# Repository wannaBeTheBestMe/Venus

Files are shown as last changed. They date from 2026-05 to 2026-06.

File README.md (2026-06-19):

# Venus — autonomous explore-and-map robot (CBL Team 6)

A PYNQ-Z2 differential-drive robot that autonomously explores a black-tape-bounded arena, finds and
classifies rock samples (size / colour / temperature), avoids cliffs and mountains, and streams its
findings to a **PyQt6 ground-station UI** that draws a live map.

This README is the **operational "how to run it" guide**. For the *how it works*:
- **[OVERVIEW.md](OVERVIEW.md)** — plain-language description of the robot and mission.
- **[ALGORITHM.md](ALGORITHM.md)** — technical reference: the EXPLORE loop, sensors, calibration, and the
  **full command + message protocol** (§10).

Active code: firmware in `motors_newest/` (C on libpynq); ground station in `UI_code.py` (PyQt6).

---

## 1. Prerequisites
- **Robot:** PYNQ-Z2 reachable over SSH at `student@10.43.0.1` (Mac link interface `en6` → board `10.43.0.1`).
  Passwordless key at `~/.ssh/pynq_key` (password is `student` if the key isn't installed).
- **Ground station (laptop):** the venv `Venus/.venv` with PyQt6 + paho-mqtt + numpy. Create it once:
  ```bash
  sh .claude/skills/launch-robot-stack/setup_venv.sh    # makes Venus/.venv and installs the 3 deps
  ```
- MQTT broker `mqtt.ics.ele.tue.nl:1883`, topics `/pynqbridge/{41|80}/send|recv` (via the on-robot ESP32).

## 2. Build & deploy the firmware (on the board)
libpynq lives **on the PYNQ**, so the firmware is built there. Stop any running `./main` first (you cannot
overwrite a running binary):
```bash
# from this Venus/ directory
ssh -i ~/.ssh/pynq_key -o StrictHostKeyChecking=no student@10.43.0.1 "pkill -f motors_newest/main; true"
scp -i ~/.ssh/pynq_key motors_newest/*.c motors_newest/*.h motors_newest/student-startup.sh \
    student@10.43.0.1:~/libpynq-5EID0-2023-v0.3.0/applications/motors_newest/
ssh -i ~/.ssh/pynq_key student@10.43.0.1 \
    "cd ~/libpynq-5EID0-2023-v0.3.0/applications/motors_newest && make clean && make"
```
The Makefile's `end.mk` applies the needed Linux capabilities (`setcap cap_sys_rawio,cap_sys_nice+ep`).
Verify with `getcap ./main`.

## 3. Run
**Easiest — the launcher skill** (opens two iTerm2 tabs: firmware over SSH + the UI in its venv):
```
/launch-robot-stack
```
**Manual — two terminals:**
```bash
# Terminal A (robot firmware)
ssh -i ~/.ssh/pynq_key student@10.43.0.1 \
    "cd ~/libpynq-5EID0-2023-v0.3.0/applications/motors_newest && ./main"
# Terminal B (ground station)
source Venus/.venv/bin/activate && python UI_code.py
```
**Autonomy on boot:** when `./main` starts *and a calibration is loaded*, it auto-enters EXPLORE after a
~5 s settle. Send **`S`** or **`HOLD`** in that window to drop to interactive command mode instead.
The UI only **listens** — operator commands go to the robot over MQTT.

## 4. First-time calibration — REQUIRED
The cliff monitor and autonomy are gated on a loaded black/white calibration. Before anything else:
```
CALBLACK     # follow the prompts: show the WHITE floor, then the BLACK tape
```
It persists to `/home/student/calblack.cfg` and reloads on boot. `CALRESET` reverts to compile-time defaults.
If you see **"cliff monitor INACTIVE until calibrated"**, run `CALBLACK`.

## 5. Common commands (send from the UI command box)
Full list + message protocol in **[ALGORITHM.md](ALGORITHM.md) §10**.

| Command | Does |
|---|---|
| `EXPLORE` | Run the full autonomous explore-and-map mission |
| `CALBLACK` / `CALRESET` | Calibrate / reset black-tape detection |
| `SWEEPQ` | 180° object sweep (reports detected objects) |
| `O` | Sweep → approach the first object → classify (size/colour/temp) |
| `RSC` | Re-sweep relocalization (heading-drift + POSFIX check) |
| `F` / `FB` | Forward until cliff / forward until an obstacle |
| `R` / `L` / `U` | Turn right 90° / left 90° / 180° |
| `MTN` | Mountain-avoidance test (strafe; halts on tape) |
| `SHL,n` / `SHR,n` | Strafe left / right n cycles |
| `TEMP` | Live temperature readout (until `S`) |
| `S` / `HOLD` | Stop the current action |
| `LOGON` / `LOGOFF` | Wireless log stream on / off |

Colour-sensor (TCS3200) demo commands also exist — `RGB`, `HSV`, `CMYK`, `SCALE,<0-3>`, `INTEG,<n>`, `WB`,
`CHROMA`, `DOM`, `NEAREST` — see ALGORITHM.md.

## 6. Two boards
A single binary serves both robots; it reads the robot id from **`~/robot_id`** at boot (falls back to `41`).
The UI supports robots 41 and 80 simultaneously; `MQTT_SAT.py` is the sole inter-robot relay.

## 7. Troubleshooting
- **Board unreachable:** `ping 10.43.0.1`; on a host-key error after an IP reuse, `ssh-keygen -R 10.43.0.1`.
- **UI won't start / `ModuleNotFoundError`:** run `setup_venv.sh`, then `Venus/.venv/bin/python -c "import PyQt6, paho.mqtt.client, numpy"`.
- **Robot won't move / "cliff monitor INACTIVE":** run `CALBLACK` (uncalibrated boots skip autonomy by design).
- **`make` fails with "text file busy" (ETXTBSY):** a `./main` is still running — stop it first (§2).

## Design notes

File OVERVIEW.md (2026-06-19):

# Venus — a robot that explores on its own and maps what it finds

> **MAINTENANCE:** This is a living, plain-language overview of the project written for **readers who
> are not involved in it** — anyone who wants to understand what the robot does without reading the
> code. **Keep it current whenever the robot's behaviour or mission changes**, and update it in the
> **same change** as the code and as its technical sibling [`ALGORITHM.md`](ALGORITHM.md).
> `ALGORITHM.md` is the detailed source of truth (for people working on the project); this file is its
> jargon-free projection. If you edit one, refresh the other so they never disagree, and keep this one
> free of code names, file paths, and protocol detail.

---

## What this is

Venus is a small **autonomous robot** — it drives itself, with no human steering it. You place it in a
walled-off area it has never seen, switch it on, and it sets off on its own: wandering the space,
finding objects, measuring each one, watching out for dangers, and continuously radioing what it
learns back to a laptop, which draws a live map. By the end you have a picture of where everything is,
without anyone ever touching a controller.

## The mission

The robot works inside an arena about **1.5 by 1.5 metres**, ringed by an edge it must not cross.
Its job, entirely on its own, is to:

- **Explore** the whole area.
- **Find an unknown number of "rocks"** (small cube-shaped objects) and, for each one, report its
  **size, colour, and temperature**, and **where it is**.
- **Avoid "mountains"** — large obstacles (think cardboard boxes) it must not bump into.
- **Never fall off a "cliff."** The arena's edges and any interior drop-offs are marked with **black
  tape on the floor**. Driving over the tape means falling — and that ends the mission. So black tape
  is an absolute "do not cross."
- **Send everything home** so a laptop can build the map in real time.

It must do all of this starting from any position, the moment it powers on — no cable, no operator
typing commands during the run.

## What's on the robot

- **Two driven wheels** (plus a small trailing wheel for balance) let it move and turn in place.
- A **downward-looking sensor** that tells floor from black tape — its cliff detector. Crucially it
  sits **ahead of the wheels**, so it spots an edge a little before a wheel would reach it.
- A **forward-looking distance sensor** that notices objects and walls in front.
- An **overhead sensor** that gauges an object's **size** once the robot is right up against it.
- A **colour sensor** and a **temperature sensor** for measuring each rock.

The same software runs on two slightly different robots — they wire their sensors up differently
inside — and it figures out which kind it's on automatically when it powers up, so one program serves
both.

The robot has no screen of its own. It has a small radio link that sends its findings to a laptop
"ground station" running the map software.

## How it explores

The robot repeats a simple, careful cycle:

1. **Look around.** Standing still, it slowly turns to scan a half-circle in front of it, noting the
   direction and distance of any objects it sees.
2. **Visit the nearest object.** It turns to face an object and creeps up to it in stages — fast at
   first, then very slowly for the last few millimetres — until it's perfectly positioned to measure.
3. **Measure it** (size, colour, temperature) and report it.
4. **Back up to where it started** the scan, reversing straight along the path it came in on (backing
   up straight is more accurate than turning around).
5. **Look again** before moving on. By re-spotting objects it already knows, it can correct small
   errors that have crept into its sense of where it is — using those objects as landmarks.
6. **Step into new ground systematically.** If the scan found nothing new, it drives forward a short
   way, and when it reaches the boundary it steps sideways one robot-width and drives back the other
   direction — a lawnmower pattern that guarantees the whole arena is covered.

This loop continues until the arena is fully covered — the robot can no longer step into new
ground in either sideways direction — or the operator stops it. It then **stops on its own**, rather
than driving forward indefinitely as the earlier version did. Throughout, the live map on the ground
station shows the robot's marker advancing lane by lane, and it still sweeps for and classifies rocks
at every position.

## How it measures a rock

Once parked right against a rock, it reads three things: the **overhead sensor** estimates **size**,
the **colour sensor** reads **colour**, and the **temperature sensor** reads how **warm** it is. All
three plus the rock's position are sent to the map.

## How it stays safe

Safety is the robot's top priority and runs constantly in the background, independent of whatever else
it's doing. A dedicated watcher reads the downward sensor non-stop; **the instant it sees black tape,
any forward motion stops immediately.** Because that sensor is mounted ahead of the wheels, the robot
halts with a margin to spare, before a wheel can cross the edge. After stopping it backs away or turns
inward to escape — it never tries to drive *around* an unknown black line, because that line might be
the arena's edge.

To avoid stopping for nothing, the watcher **double-checks** each reading: it takes several quick
samples and uses the middle value, and only treats the floor as a cliff after a few black readings in
a row. This filters out the occasional electrical "blip" (which previously made it stop on plain white)
while still reacting to a real edge within a fraction of a second — so it stops when it should, and
only when it should.

It also handles two trickier situations: if a **mountain** blocks the way, it backs off and sidesteps
until the path is clear; and if it gets **boxed into a corner** — pinned between a cliff and an
obstacle — it does a careful scan for the most open direction and commits to a longer move to break
free, giving up gracefully (and stopping) if there's genuinely no way out.

The robot also monitors for cliff/boundary tape during sideways shuffle manoeuvres. If the downward
colour sensor detects the black boundary tape while the robot is strafing sideways around a mountain,
the robot stops immediately and defers to its normal cliff-recovery routine. This closes a previously
known safety gap where a mountain near the arena boundary could cause the robot to strafe off the edge.

## What the operator sees on the ground station

When EXPLORE starts, the ground station immediately shows **"[EXPLORE] mission started"** in the
log. As the robot sweeps each position, detected rocks appear as green dots on the map — every
cycle, not just at the end. When the robot drives to a rock the marker moves forward on the map;
when it returns it retraces the path backward. After each forward hop (when the sweep found
nothing) the marker advances on the map. If the robot gets trapped in a corner, the log shows
**[TRAP] escaping** (amber), then **[TRAP_OK] escaped** (cyan) or **[TRAP_FAIL] mission stopped**
(red) if all attempts fail. If the heading drifts and the re-sweep corrects it, the log shows
**[DRIFT] heading corrected X° from N refs** (amber) — this appears every time a correction is
applied, not only during the RSC test command. The RSC test command now shows the same green
rock-dot display as a normal sweep.

## The bigger picture

Everything the robot senses is sent wirelessly to a laptop, which acts as the **ground station**. The
laptop draws a live map: the robot's path, the rocks it found (with their measurements), the walls and
boundary it traced, and the hazards to avoid. The system is even built to track **two robots at once**
on the same map, each shown in its own colour — a stepping stone toward having robots cooperate, which
is planned future work.

## What's genuinely hard about this

The clever, difficult parts are mostly invisible:

- **Knowing where it is without GPS.** Indoors there's no satellite positioning, so the robot
  estimates its position by counting how far its wheels have turned. Small errors build up over time
  ("drift"), so it periodically re-checks against objects it has already seen and nudges its estimate
  back in line.
- **Telling a wall from an obstacle.** A patch of black tape could be the outer boundary or just a
  small drop-off in the middle of the arena. The robot treats *all* black as dangerous immediately,
  and the map software later works out which black marks form the boundary loop and which are isolated
  interior hazards.
- **Not falling while squeezing past things.** Moving close to edges and obstacles without a wheel
  ever crossing the tape takes careful, slow, well-timed motion.
- **Separating objects that overlap.** The forward sensor sees a fairly wide cone, so two nearby
  objects can blur together; the robot uses the pattern of distances as it scans to tease them apart.

## Current status and honest limits

- It currently runs as a **single robot**; coordinated **two-robot teamwork is planned but not done**.
- Its sense of position **drifts** over long stretches with no landmarks in view; it corrects locally
  but does not build a perfect global map.
- Distinguishing the boundary from interior hazards is a **best-effort guess** made after the run, not
  a guarantee — though the live "don't cross black" safety rule is always in force regardless.
- It can only see **nearby** objects on each scan, so coverage comes from many short hops rather than
  one long-range view.
- There is **one known edge-case safety gap** that the team is tracking.

## Glossary

- **Arena** — the walled-off area the robot explores (about 1.5 × 1.5 m).
- **Cliff** — a drop-off the robot must not cross, marked by black tape (the outer boundary counts as a
  cliff too).
- **Rock** — a small cube the robot finds and measures (size, colour, temperature).
- **Mountain** — a large obstacle (e.g. a box) the robot must avoid hitting.
- **Sweep / scan** — turning in place to look around and locate objects.
- **Drift / dead-reckoning** — estimating position by counting wheel motion; accumulates small errors.
- **Ground station** — the laptop that receives the robot's reports and draws the live map.
- **Autonomous** — acting on its own, with no human steering during the run.

---
*Keep this file current — see the MAINTENANCE note at the top. Its technical counterpart is
[`ALGORITHM.md`](ALGORITHM.md).*

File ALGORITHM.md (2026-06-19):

# Autonomous explore-and-map robot — algorithm & system overview

> **MAINTENANCE:** This file is the living description of how the robot works. **Keep it updated
> whenever the firmware's or UI's functionality changes** (new/changed commands, sensors,
> detection logic, hazard handling, calibration, message protocol, etc.). It targets someone new
> to the project who needs the important details. Active firmware: `motors_newest/`; UI:
> `UI_code.py`. (Earlier boundary-tracing work — `motors_xshut` / the "Increment 1/2" plans — is
> archived and superseded by the explore-and-map system described here.)

## 1. The system
A **PYNQ-Z2** drives a **differential-drive robot** (two stepper wheels + trailing caster).
Firmware is C on **libpynq**, in `motors_newest/` (`main.c`, `main_header.h`, `explore.h`,
`3_sensors_header.h`, `shuffle.h`). The robot is **autonomous on boot** once the boot service is
installed+enabled: the launcher `student-startup.sh` + systemd unit `student-startup.service` are
defined in `motors_newest/` and installed on a board via `install-startup-service.sh` (enabling is a
deliberate motion-safe step — a calibrated reboot drives within ~8 s). It launches `./main` on
power-up (no cable), and after `READY`
— provided a calibration is loaded — the robot **auto-enters EXPLORE** following a ~5 s
settle/opt-out window during which the laptop only listens. A wireless `S`/`HOLD` in that window
drops to the interactive UART command loop instead; uncalibrated boots skip autorun and fall through
to the command loop. Commands in and telemetry/logs out travel wirelessly: firmware
`send_message()` → UART → an **ESP32 "pynqbridge"** → **MQTT** (`mqtt.ics.ele.tue.nl`, topics
`/pynqbridge/{41|80}/send|recv`) → a **PyQt6 ground-station UI** (`UI_code.py`) that integrates
pose and draws the map.

The UI supports **two simultaneous robots** (modules 41 and 80). Each robot has an independent
per-robot state dict (`self.bots[robot_name]`): heading, provisional boundary crossings, sweep
markers, boundary segments, and black contacts. A shared `self.cliffs` layer merges hazards from
both robots onto one map. Robot attribution is topic-based (MQTT topics `/pynqbridge/41/send` and
`/pynqbridge/80/send` each carry a `robot_name`); payloads are wire-identical between the two.
The relay between robots is performed exclusively by `MQTT_SAT.py` (loop-guarded with a `[B]`
prefix); the UI does not relay.

## 2. Mission context
A ~**150×150 cm arena**. Explore it; find and classify **rocks** (small cubes); avoid **mountains**
(cardboard boxes ≥30 cm — don't collide); respect **cliffs**. Cliffs and the arena **boundary are
black tape**; the boundary is conceptually a cliff and the footprint crossing it = falling off =
mission loss. Isolated ~10×10 cm black patches are interior cliffs to route around. Each black contact is
reported (`BLACKPT,heading,run`) and the UI now **classifies** black offline at end of run: a
**continuous run** of contacts (the robot tracing the tape loop) is fit as the **boundary polygon**;
an **isolated patch** (a single, lone contact) is drawn as an **interior cliff** (red X). Safety is
unchanged — *all black still halts forward motion the instant it is seen*; classification is purely
a mapping/visualization layer.

## 3. Sensors
- **Downward TCS3200** — a full-feature colour sensor used primarily for **black detection**
  (cliffs/boundary). Managed entirely by **`motors_newest/tcs3200.h`** (header-only C module,
  feature-parity with github.com/nthnn/TCS3200). The module owns all GPIO primitives, calibration
  arrays, colour-space conversions, and the global state struct `g_tcs`. `main_header.h` and `main.c`
  call the module API; `detect_black()` in `main_header.h` is re-based onto
  `tcs3200_read_clear_fast()`.

  Black detection uses the **clear (unfiltered) channel** only (black → low reading). Mounted
  **ahead of the wheels** → lookahead before a wheel reaches an edge. Each read is a **median of
  `DETECT_SAMPLES` pulse measurements** (`tcs3200_median_pulse_n`): the single busy-wait pulse
  timing (`tcs3200_pulseIn_LOW`) is corrupted when the OS preempts the monitor thread
  mid-measurement — the gap inflates the reading, and an inflated clear pulse maps toward black
  (false positive on white). The median rejects those outliers in both directions, removing the
  false positives without risking a false negative. (Filter-settle happens *before* the read;
  `detect_black` keeps CLEAR selected and re-asserts it idempotently with no delay, so cliff
  polling stays fast.) `integration_time` = median sample count N (API parity with the original).
  Frequency scaling (S0/S1) is controlled via `tcs3200_frequency_scaling()`; boot default is
  `TCS3200_SCALING_2PCT` (S0=H, S1=L — preserves the original hardcoded GPIO levels).
- **Forward VL53L0X** — objects/obstacles ahead. Range ≤ 500 mm, **wide ~25° cone**.
- **Overhead VL53L0X** (≤ 90 mm) — object **size** classification once approached.
- **Front TCS34725** — rock **color** (red/green/blue/black/white).
- **Thermistor on ADC0** — rock **temperature** (°C; Steinhart-Hart). Read at the close/stop
  position during classification; standalone live readout via `TEMP` (loops until `S`).

**Dual I2C-sensor backend (auto-detected at boot).** The three I2C sensors above (forward + overhead
VL53L0X, color TCS34725 — all natively 0x29) are disambiguated one of two ways depending on the robot:
**XSHUT** (re-address to 0x30/0x31 via XSHUT pins — the default/current robot) or a **PCA9548A I2C mux**
at **0x70** (the older robot — all three at 0x29, selected by channel). `all_sensors_init` probes 0x70
once: ACK → mux backend (`mux_scan_vl53_color` assigns roles by channel — **forward = lower VL53 channel,
overhead = higher**, overridable via `~/sensor_channels` = `fwd oh [color]`), NAK → XSHUT backend. The
mission code is unchanged — only the transport inside the `read_distance_*`/`read_color` helpers branches
(`vl53_read_raw_mm`). The downward TCS3200 (cliff) and thermistor are **not** on the mux. Verify the mux
robot's forward/overhead mapping with the `MUXMAP` command (~200 mm from a wall → forward ≈ 200, overhead
OOR). The boot log prints `SENSOR BACKEND: MUX (fwd chN / oh chM / color chK)` or `XSHUT`.

## 4. Low-level conventions
- **Stepper motion is non-blocking** and buffers only one "next" command — issuing faster than
  steps execute silently drops them. Two helpers tame this (`main_header.h`):
  - `stepper_halt()` = `stepper_reset()`+`stepper_enable()` — cancels in-flight + queued steps now.
  - `move_batch_until(steps, speed, stop_fn)` — issues one batch, **polls to completion**, halts the
    instant `stop_fn()` fires (prevents step-loss *and* gives prompt stops).
- **Calibration:** 1600 steps/rev; `MOVE_UNIT = 500` steps (~6 cm). In-place **turns run at
  `SPEED_ULTRA_SLOW`** (no slip) using no-slip-calibrated counts `TURN_90_STEPS_US = 640` /
  `TURN_180_STEPS_US = 1280` (empirically tuned via the 9×U realignment + U×2 confirm method).
  `sweep_rotate` (SWEEPQ) now shares this calibration (`TURN_180_STEPS_US/180` steps/°) and
  accumulates the fractional step across the 0.5° increments, so the sweep covers exactly 180°,
  returns to origin, and reported bearings match the physical heading.
- **Orientation** (`orientation_t`): quadrant `ort` (1=N,2=E,3=S,4=W) + `theta` (0–90°);
  `get_heading = (ort−1)·90 + theta`. Firmware updates it on *deliberate* turns; the UI keeps live
  (x,y,heading) by integrating `STEPS`/`ORT` (`STEPS,n` = forward displacement as a **`MOVE_UNIT`
  chunk count**, converted in the UI via `CM_PER_UNIT = MOVE_UNIT·CM_PER_STEP` ≈ 6.15 cm/chunk —
  NOT raw steps; `ORT,ort,theta` = heading snaps).
- **Black calibration** (`CALBLACK`): operator shows the **white floor** then **black tape**;
  firmware stores clear-channel min/max, **persists to `/home/student/calblack.cfg`**, loads at
  boot. `CALRESET` restores compile-time defaults and deletes the file.

## 5. Global cliff-stop (safety spine)
A **background thread** continuously reads the downward sensor and sets `g_black` on black — but only
after **`BLACK_CONFIRM` (3) consecutive** black reads (debounce); any white read resets the run. So a
single stray reading can't latch a false cliff, while a real cliff (read black continuously) still
latches within ~3 polls (tens of ms ≈ sub-mm of travel at explore speed, far inside the wheel-lead
margin). It is the sole owner of that sensor (commands needing raw color reads pause it). **Every
forward-translating command halts the instant `g_black` is set**, so the robot stops before a wheel
crosses an edge (the ahead-of-wheels mounting gives the margin). It **auto-starts at boot only if a
calibration is loaded** (an uncalibrated monitor could read the floor as black and freeze motion).
The **same `cal_loaded` guard** that gates the cliff-monitor auto-start also gates F1 AUTORUN —
uncalibrated → monitor OFF *and* no autonomous explore (a single consistent safety gate).
Recovery from a black halt is a **reverse or turn** — intentionally *not* gated.

**In-place turns suspend cliff latching** via a re-entrant counter `g_black_suspend` (> 0 → monitor
skips `detect_black`, resets the consecutive-black debounce, and loops). Guard helpers
`turn_guard_begin/end` bracket each reorientation turn (R, L, U, the two `turn_180()` calls in the
MOVE handler, and the `exp_rotate_deg` / `exp_rotate_rel` explore helpers). Only the **outermost**
begin/end pair clears `g_black` — nested turns don't churn it. `turn_guard_end` clears `g_black` so
the monitor re-confirms a real ahead-cliff (within `BLACK_CONFIRM` ≈ 60 ms) before the next forward
command relies on it. The **sweep rotation** (`sweep_rotate`) is intentionally **not** gated —
`sweep_collect` and `escape_scan` rely on black during the sweep for abort / side-selection logic.
Tradeoff: a cliff directly under a wheel mid-rotation is not caught until the turn ends; mitigant is
that turns are in-place and follow a stop (no translation toward an edge), and `turn_guard_end`
re-arms detection before any forward move — the same risk already accepted for recovery turns.

**Latched-flag lifecycle (avoid stale-disable across commands):** both `g_stop` (operator `S`,
latched in `exp_check`) and `g_black` (sticky-set by the monitor, never self-cleared) persist
until explicitly reset. To stop a stale flag from silently disabling a freshly-issued command:
`g_stop` is reset at **command dispatch** (every command); `g_black` is acked on-halt by the fast
forward commands (`F`/`FB`/`O`/`MOVE`/`R`/`L` — self-heal) and **cleared at entry** by the slow
diagnostic commands (`EXP1`/`ADV`/`SWEEPQ`) where the monitor safely re-asserts a real cliff within
~one poll. `g_black` is **never** cleared globally at dispatch (that would open a re-assert window
on the fast `SPEED_FAST` moves).

## 6. The EXPLORE algorithm (`run_explore`, loops until operator `S`)
On entry: emits `EXPLORE` (UI shows mission started).
1. **Sweep.** From the current pose ("scan origin"), rotate **in place through 180°** about the
   current heading, in fine increments; the forward sensor profiles the surroundings and the robot
   extracts **discrete objects** (bearing-relative-to-center + distance). Mark the scanned
   semicircle explored (`REGION`). After each sweep: emits `OBJN,n` + per-object `OBJ,rel_deg,dist_mm`
   (UI renders sweep dots every cycle, not just on SWEEPQ).
2. **If objects found**, for each: rotate to its bearing → **approach** in two phases (monitored;
   `heading_update` silently re-aims at the object without disturbing tracked heading): coarse to
   **40 mm** at `SPEED_ULTRA_SLOW`, then a fine creep to **15 mm** at `SPEED_ULTRA_ULTRA_SLOW`
   (slowest), then a fixed open-loop **~5 mm** nudge so the **overhead sensor parks over the rock** → 
   **classify** (front color + overhead size). **Rock** → send `FOUND_ROCK,size,color`. **Mountain**
   → run avoidance. After approach (ADV_DONE): emits `STEPS,moved` + `ORT` (UI marker drives to
   rock). Then **return to the scan origin** by **driving straight in reverse** along the
   approach path (no about-face turn — eliminates the 180° turn error that skewed the return),
   then restore heading. After normal return: emits `STEPS,-moved` + `ORT` (UI marker retraces back
   along the trail; negative sign drives the marker in reverse). **Re-sweep loop-closure**
   (`resweep_correct`): after each return, sweep again and match the still-present rocks against the
   original sweep — **refresh** the not-yet-visited objects' bearings from the new sweep (so the next
   approach aims where the rock actually is now, robust to rotation **and** small position drift) and,
   when ≥2 rocks match, apply the **median bearing offset** to the tracked heading so `ori`/UI stay
   truthful and the next return physically re-centres; emits `DRIFT,deg,n` unconditionally when
   correction is applied (both in-loop and RSC paths). When ≥2 non-collinear matched pairs are
   available (bearing spread ≥20°), it also computes a **translation fix** (`POSFIX,dx_mm,dy_mm`):
   the least-squares mean of the per-pair displacement vectors in the robot's local frame (dx=right,
   dy=fwd). Emitted during `RSC` diagnostics; the UI handler applies it to the tracked robot
   position. Collinear rock geometry (spread <20°) is logged as "unobservable, skipped" and no fix
   is applied. Then continue.
3. **If none** — F2 boustrophedon (lawnmower) coverage:
   1. **Lane run:** advance in `EXP_ADVANCE_MM` (300 mm) hops via `advance_monitored` until a
      boundary cliff (`ADV_BLACK`) or mountain (`ADV_MOUNTAIN`) blocks progress, or until the hop
      budget (`EXP_BOUS_HOP_BUDGET = 60`) is reached. On each successful hop (ADV_DONE, moved>0):
      emits `STEPS,moved` + `ORT` (UI marker advances one hop).
   2. **Lane transition:** at each boundary, capture the lane heading *before* the hazard handler runs
      (`lane_heading = get_heading(ori)`), run the existing hazard handler (recoil + interior turn),
      `g_black_ack()` any stale cliff latch, then call `bous_sidestep(ori, lane_heading, ±90°)`. The
      sidestep targets **absolute** headings via `rotate_to_heading`: it turns to `lane_heading ± 90°`
      (a true lateral step), advances one `EXP_ADVANCE_MM` lateral hop (`advance_monitored`,
      cliff-safe), then turns to face the reversed lane (`lane_heading + 180°`). On success it emits
      `ORT` **then** `STEPS,moved` (so the marker steps in the lateral heading) and alternates the
      preferred direction so coverage is symmetric. On a blocked sidestep the hazard is handled, the
      latch cleared, and `lane_heading` restored so the opposite direction is tried cleanly.
      *(Targeting the pre-hazard `lane_heading` is what makes this a true lawnmower, not an inward
      spiral: `handle_black` rotates the body ~90° on its own, so a delta-based turn would compound.)*
   3. **Termination — `EXPLORE_DONE`:**
      - *Primary:* both sidestep directions blocked for `EXP_BOUS_EXHAUST_LANES` (2) **consecutive**
        lane-ends — arena exhausted; logs `BOUS: N consecutive blocked lanes`. Between the first such
        event and the limit, `escape_trap` relocates the robot to open space and coverage resumes; the
        `g_bous_blocked` counter resets on any forward hop or successful sidestep (so a concave corner
        doesn't falsely declare the arena done).
      - *Secondary:* `g_bous_hops >= EXP_BOUS_HOP_BUDGET` (60) — hard budget bound (guarantees a stop
        even on a logic error; logs `BOUS: hop budget exhausted`).
      - *Tertiary:* existing `escape_trap` give-up (`EXP_TRAP_MAX_TRIES` exceeded) — inescapably
        cornered; returns `ADV_STOP`.
      - *Operator S/HOLD:* `g_stop` set inside `advance_monitored`/`exp_check()`.
      All `break` paths fall through to the single `EXPLORE_DONE` emit.
   The lane transition targets **absolute headings** off the pre-hazard `lane_heading` (via
   `rotate_to_heading`), so `handle_black`'s own ~90° interior turn cannot corrupt the lateral
   direction. No raw `stepper_steps` anywhere in the new code.

**Hazard handlers:**
- **Cliff** (`handle_black`): halt immediately (cancel in-flight steps **first**), log a 10×10 cm
  **no-go box** (`NOGO`), back straight off, turn toward the interior — never circle to the far side
  of an unknown black streak (could be the boundary). Each cliff halt also emits
  **`BLACKPT,heading,run`** alongside `NOGO` (additive — same pose, no behavior change), where `run`
  is the count of consecutive black contacts without intervening forward progress (`g_black_run`,
  reset on a net-progress hop). The UI uses `run` to tell a boundary trace (long run) from a lone
  interior cliff (run = 1). `g_black_run` is distinct from F3's `g_haz_streak` (the two coexist:
  streak = cliff+mountain trap detector, run = black-only continuation hint).
- **Mountain** (`avoid_mountain`): back up, report, **shuffle sideways**, re-check forward; repeat
  until clear.
  > **BUG-2 fix (2026-06-18):** `shuffle_sideways` (and its sub-primitives `steps_blocking`,
  > `shuffle_step_left`, `shuffle_step_right`) are now cliff-gated. `steps_blocking` polls `g_black`
  > inside its wait loop and calls `stepper_halt()` on detection. `shuffle_sideways` clears the stale
  > latch once at entry (matching the `escape_scan` / `g_black_ack` discipline) then returns 1 on
  > abort. `avoid_mountain` breaks immediately on a black hit rather than continuing to strafe. All
  > callers (`avoid_mountain`, `SHL`, `SHR`, `MTN`) are covered by the single primitive gate. The
  > sideways strafe is now as cliff-safe as the forward motion primitives.
- **Trap/corner escape** (`escape_trap`, F3): consecutive hazards without net forward progress
  (`g_haz_streak` ≥ `EXP_TRAP_HAZ_LIMIT`) mean the robot is boxed in / ping-ponging between the cliff and
  mountain handlers. It then runs a **bounded in-place open-direction scan** (`escape_scan`: pivots ±90°,
  returning to centre between halves so it never circles past an unknown black streak), rotates to the
  **most-open heading**, and commits a longer (`EXP_TRAP_COMMIT_MM`) monitored move to break out. Bounded
  by `EXP_TRAP_MAX_TRIES` — on give-up it stops the run. Emits `TRAP` / `TRAP_OK` / `TRAP_FAIL`. UI
  handlers added (UIFB): `TRAP` → amber "[TRAP] escaping", `TRAP_OK` → cyan "[TRAP_OK] escaped",
  `TRAP_FAIL` → red "[TRAP_FAIL] mission stopped" (previously emitted but silently ignored by the UI).

## 7. Sweep object detection (the subtle part)
The forward cone smears each object across ~25°, so naive "any in-range run = one object" merges
neighbors. The detector (`sweep_collect`):
- **0.5° steps, slow, blocking** (truly covers 180°, samples settled);
- **raw** forward reads — deliberately **no** sample-to-sample delta rejection (big jumps are real
  as the beam pans between objects at different ranges);
- groups readings while within a distance tolerance of the object's running mean, and **splits on a
  sustained shift to a new distance level** (separates overlapping-cone objects at different ranges);
- requires an object to **persist** several steps (rejects spikes); reports **bearing at the nearest
  reading** + that minimum distance.
- *Physical limit:* two objects at ~equal distance within one cone-width can still merge (sensor
  resolution, not a bug).
- *Logging:* on normal completion `sweep_collect` logs `SWEEP: N obj, closest=… mm`; if it aborts
  early it logs the **reason at the source** — `SWEEP: aborted on BLACK/STOP at ~<deg>` (so every
  caller — `RSC`, `SWEEPQ`, `EXPLORE`, the re-sweep — explains a mid-sweep stop instead of failing
  silently). Callers no longer disguise a `−2/−3` abort as "0 objects."

## 8. Object classification (`classify_object`)
Approach two-phase to ~15 mm at the slowest speed, then a fixed open-loop ~5 mm nudge (forward sensor is unreliable below ~15 mm), parking the overhead over the rock. Then: front color sensor → color; overhead sensor (10 readings) → size; thermistor (ADC0) → temperature. A rock is reported as `FOUND_ROCK,size,color,temp` (temp `n/a` if the ADC read is invalid).
All forward approaches share one function, `approach_object` (`EXP1`, `EXPLORE`, `O`, and `FB`), so the coarse-then-fine creep, cap, and cliff/stop handling are identical everywhere.
Hardened against bad sensor data: overhead sampling is **bounded** (`EXP_OH_MAX_ATTEMPTS`) so a
stuck/disconnected sensor can't hang; **out-of-range readings are excluded from the distance
average** (counted only via the "tall / no-top" rule); returns an error rather than guessing if too
few valid samples. Output: size ≈ 3 cm or 6 cm, or **mountain** (overhead average in a calibrated
bin), or error.

## 9. UI (`UI_code.py`)
PyQt6 scene (±150 cm, both robots start at center). Two robot markers (Robot41=cyan,
Robot80=magenta) each have independent pose state (`self.bots[robot_name]["angle"]`, `.marker`,
`.pending_pt`, `.sweep_items`, `.boundary_segments`, `.corner_angles`, `.tape_hits`,
`.black_contacts`). A shared `self.cliffs` layer collects hazard points from both robots.
Integrates pose from `STEPS`/`ORT` (`STEPS,n` forward displacement as a `MOVE_UNIT` chunk count, converted via `CM_PER_UNIT`;
`ORT,ort,theta` heading snaps); renders the robot, fitted **boundary** polygons
(total-least-squares per-robot), **cliffs** (red X, shared), **no-go boxes**, **mountains**
(amber ring), **rocks** (`FOUND_ROCK`), **explored semicircles** (`REGION`), and **swept objects**
(`OBJ` markers with a distance label + a line from the robot — per-robot, cleared per sweep). A
"DATA STREAM" panel shows all wireless **`LOG`** lines color-coded by source robot.

At **`EXPLORE_DONE`** the UI runs `classify_black_contacts` per robot: it clusters that robot's
`BLACKPT` contacts (per-robot, since odometry drift differs), classifies each cluster as a boundary
run or a lone interior cliff, and draws onto the **shared** boundary-polygon / `cliffs` layers.
Live contacts show as faint amber dots as they arrive.

## 10. Commands
- **`EXPLORE`** — the full autonomous loop (stop with `S`).
- **TCS3200 diagnostic/demo commands** (added with feature-parity refactor; pause the cliff monitor
  while reading, then restore it): `RGB` (emit `RGB,r,g,b` — calibrated 0-255 per channel);
  `HSV` (emit `HSV,h,s,v`); `CMYK` (emit `CMYK,c,m,y,k`); `SCALE,<0-3>` (set frequency scaling:
  0=power-down, 1=2 %, 2=20 % default, 3=100 %); `INTEG,<n>` (set integration time = median
  sample count, 1-16); `WB` (capture white-balance reference, emit `WB,r,g,b`); `CHROMA` (emit
  `CHROMA,f`); `DOM` (emit `DOM,RED|GREEN|BLUE` — dominant channel); `NEAREST` (emit
  `NEAREST,WHITE|BLACK|RED|GREEN|BLUE` — classify current colour against 5 arena references by
  Euclidean RGB distance).
- **Per-behavior test sub-commands:** `CALBLACK`/`CALRESET`, `CLIFFCHK` (live black readings),
  `MON`/`MONOFF` (cliff monitor), `HU2` (drift-correction), `SWEEPQ` (sweep + report objects),
  `EXP1` (approach+classify one object), `RET` (out-and-back), `ADV` (monitored 300 mm advance),
  `MTN` (mountain avoidance), `NUDGE` (the open-loop ~5 mm final approach step in isolation),
  `RSC` (re-sweep drift check: sweep → approach one rock → return → re-sweep, reports `DRIFT`/`DOBJ`;
  also emits `POSFIX,dx_mm,dy_mm` — translation fix, integers, robot-local frame — when ≥2
  non-collinear matched rocks are available; skips with a log if geometry is degenerate. Like
  `SWEEPQ`, RSC **isolates its in-place sweeps from the cliff monitor** (`exp_mon_stop`+`g_black=0`
  around each sweep — an in-place rotation can't translate toward a cliff) and **re-arms the monitor
  for the translating approach + return**, so it no longer freezes mid-sweep near tape. A sweep that
  does abort is now logged with its reason — see §7),
  `ESCAPE` (F3 trap/corner-escape routine in isolation: forces a stuck state and runs the open-direction
  scan + commit-move escape).
- **Manual moves** — `F`, `FB`, `O`, `MOVE`, `R`/`L`, `STOPBLACK` — all honor the global cliff-stop.
- **Autonomy / boot:** no command is needed for normal operation — after `READY` (calibration
  loaded) the robot auto-enters EXPLORE following a ~5 s settle window; a wireless `S`/`HOLD` during
  that window opts out to manual command mode (uncalibrated boots skip autorun). An optional
  `HELLO,<id>` may be emitted near `READY` (advisory; attribution is topic-based). The run-on-boot
  launcher is `student-startup.sh`, wired to boot by the systemd unit `student-startup.service`
  (both in `motors_newest/`; install via `install-startup-service.sh`, then `enable` per the staged test).
- **Logging:** `LOGON`/`LOGOFF` toggle the wireless `LOG` mirror (off for the scored demo).

### Message protocol (firmware → UI), selected
`STEPS,n` (forward displacement as a `MOVE_UNIT` **chunk count**; UI converts via
`CM_PER_UNIT = MOVE_UNIT·CM_PER_STEP` ≈ 6.15 cm/chunk — NOT raw steps. Firmware does **not** emit
`ODOM` — a legacy/dead `ODOM` handler lingers in the UI but is never exercised) ·
`ORT,ort,theta` (orientation snap; firmware `ort` 1=N, 2=E, 3=S, 4=W; UI maps to scene degrees
`{1:0, 2:90, 3:180, 4:270}` then adds `theta` — the old `{1:90,2:180,3:270,4:0}` map was a 90°
systematic error, fixed in F8) ·
`REGION,radius_cm` ·
`OBJN,n` then `OBJ,rel_deg,dist_mm` (swept objects) · `FOUND_ROCK,size,color[,temp]` ·
`MOUNTAIN,size_cm` · `NOGO` (10×10 cm cliff box — emitted by `handle_black` in the mission AND by the
test/diagnostic commands `F`/`FB`/`MOVE`/`R`/`L`/`O`/`SHL`/`SHR`/`STOPBLACK`/`EXP1`/`ADV`/`NUDGE` when
they halt on black, via the pure-UI helper `report_nogo`, so the operator sees the cliff regardless of
which command tripped it) ·
`BLACKPT,heading,run` (F5; per black contact, paired with `NOGO`, additive — heading in deg,
run = consecutive-black count) ·
`POSFIX,dx_mm,dy_mm` (F4 translation fix; dx=right, dy=fwd, mm, ints; non-collinear rocks only) ·
`EXPLORE` (UIFB; autonomous mission started — UI shows "[EXPLORE] mission started") ·
`DRIFT,deg,n` (UIFB; heading corrected by re-sweep, emitted unconditionally when nd≥MIN_REFS, both
in-loop and RSC paths; UI shows "[DRIFT] heading corrected X° from N refs" in amber) ·
`TRAP`/`TRAP_OK`/`TRAP_FAIL` (F3 trap-escape status; UIFB: now handled by UI — amber/cyan/red) ·
`HELLO,<id>` (optional boot identification ping near `READY`; advisory) ·
`EXPLORE_DONE` · `LOG,<text>`.
Note: `OBJN,n` / `OBJ,rel_deg,dist_mm` / `STEPS,n` / `ORT,ort,theta` now also apply within the
EXPLORE command (not only SWEEPQ/O/FB/F) — see §6 emit notes.

**Attribution:** each message is attributed by MQTT topic (Robot41 = `/pynqbridge/41/send`,
Robot80 = `/pynqbridge/80/send`). Payloads are format-identical; `robot_name` is set by the
`MQTTWorker` that received the message. Inter-robot relay is handled solely by `MQTT_SAT.py`.

## 11. Known limitations / caveats
- **Dead-reckoning drift**: within a region the per-object **re-sweep loop-closure**
  (`resweep_correct`) corrects accumulated **angular** drift (heading) AND computes a **translation
  fix** (`POSFIX`, F4) from the bearing+distance displacement of matched rocks. The UI applies the
  POSFIX to realign the robot overlay. Requires ≥2 non-collinear rocks (bearing spread ≥20°);
  degenerate geometry is skipped. Between-hop drift over large distances (no rocks in view) and
  global SLAM remain unsolved.
- **Boundary vs interior cliff** is now classified **offline at end of run** from `BLACKPT` contact
  runs (continuous run → boundary polygon; lone patch → cliff X). It is a heuristic on run length +
  spatial clustering, not a guarantee: a boundary explored in short disconnected bursts, or a large
  interior patch grazed repeatedly, can be mis-binned. The live cliff-stop is unaffected — all black
  always halts forward motion.
- **Angular resolution** capped by the forward sensor's ~25° cone (close, equal-distance objects can
  merge).
- **Sweep reach** is ≤ ~0.5 m, so a sweep only sees nearby objects; coverage comes from 300 mm hops.
- Overhead classification is **hardened** (bounded attempts; out-of-range excluded from the
  distance average; returns an error instead of guessing/hanging). All callers — `EXP1`, `O`, and
  `EXPLORE` — share this via `classify_object`, and the `O`/`EXP1` approach loops are step-capped
  (`EXP_APPROACH_CAP`).

---
*Keep this file current — see the MAINTENANCE note at the top.*

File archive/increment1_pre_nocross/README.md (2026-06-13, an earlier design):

# Increment 1 — pre-no-cross snapshot

These files implement the **Increment-1 plan** (detection + corner-finding + mapping
mechanics). They are a frozen snapshot taken before the Increment-2 redesign.

⚠️ **NOT cliff-safe.** The FOLLOW state in `boundary.h` traces a zigzag that
*straddles / crosses* the black tape. That is fine for bench-validating detection
and mapping on flat tape, but on the real arena the boundary is a cliff and
crossing it counts as falling off (mission loss). Increment 2 replaces FOLLOW with
an inside-only edge-hug and adds an ACQUIRE phase + forward-obstacle avoidance.

- Full Increment-1 spec:  `~/.claude/plans/increment1-pre-nocross.md`
- Active (Increment-2) plan: `~/.claude/plans/can-you-analyze-the-noble-book.md`
- Git restore point: tag `increment1-pre-nocross`

Files: `boundary.h`, `main.c`, `UI_code.py` (verbatim copies of the live files at
snapshot time). Do not edit these — they are the historical record.

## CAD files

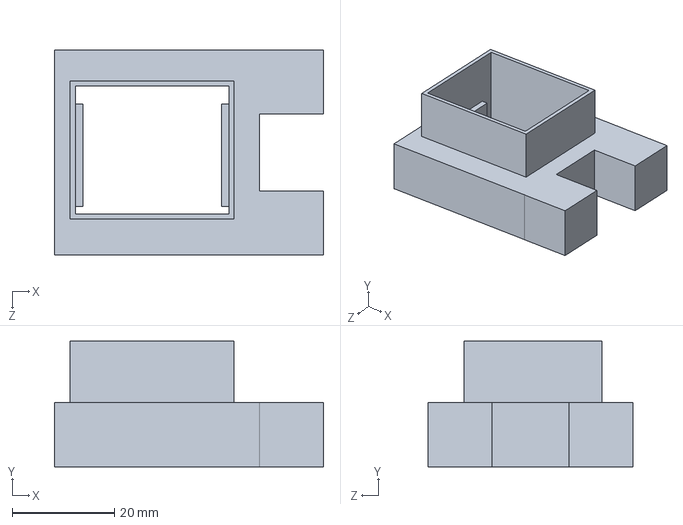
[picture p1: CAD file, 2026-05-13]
Sensor_mount/Draft 1.SLDPRT
52.5 x 24.5 x 40.0 mm

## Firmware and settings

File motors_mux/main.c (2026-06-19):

#include "main_header.h"
#include "shuffle.h"
#include "explore.h"

struct rock_data_t {
	enum e_rock_color color;
	int32_t size;
	float temp;
};

// Bounded UART frame reader for the AUTORUN soft-stop window. Mirrors
// read_uart_message's framing (4-byte LE length + payload, MAX_MSG_LEN clamp)
// but never busy-waits forever: each per-byte wait is capped by budget_ms.
// Returns 1 with a complete message in msg, or 0 on timeout/partial frame
// (so a stray/corrupt byte during boot can't hang autonomy). main_header.h:157.
static int autorun_read_bounded(char msg[], int budget_ms)
{
	int spent = 0;
	uint32_t len = 0;
	for (int i = 0; i < 4; i++)
	{
		while (!uart_has_data(UART0))
		{
			if (spent >= budget_ms) return 0;
			sleep_msec(2); spent += 2;
		}
		len |= ((uint32_t)uart_recv(UART0) << (8 * i));
	}
	if (len >= MAX_MSG_LEN) len = MAX_MSG_LEN - 1;
	for (uint32_t i = 0; i < len; i++)
	{
		while (!uart_has_data(UART0))
		{
			if (spent >= budget_ms) return 0;
			sleep_msec(2); spent += 2;
		}
		msg[i] = uart_recv(UART0);
	}
	msg[len] = '\0';
	return 1;
}

// F-local forward batch with non-progress detection. Issues one MOVE_UNIT batch
// and polls to completion exactly like move_batch_until, BUT distinguishes a real
// batch (the stepper actually consumed steps) from a dropped/instant-done batch
// (the robot is pinned on tape and stepper_steps silently dropped the command, so
// stepper_steps_done() is true on the first poll). Used ONLY by the "F" handler;
// move_batch_until is left untouched for every other caller.
//
// Returns:
//   F_BATCH_MOVED  (0) - a real MOVE_UNIT of motion completed (advance the count)
//   F_BATCH_STOP   (1) - stop() fired (g_black cliff or operator S) - halted now
//   F_BATCH_NOPROG (2) - batch did NO motion (dropped/instant-done); robot pinned.
//                        The stop() condition is STILL checked before returning, so
//                        a real cliff that latched on this batch is never missed.
#define F_BATCH_MOVED   0
#define F_BATCH_STOP    1
#define F_BATCH_NOPROG  2
static int f_batch_forward(int steps, int speed, int (*stop)(void))
{
    stepper_set_speed(speed, speed);
    stepper_steps(steps, steps);

    // Readback the steps PENDING in the just-issued command. On a real batch the
    // full magnitude is still queued here; on a dropped/instant batch it reads ~0.
    int16_t rl = 0, rr = 0;
    stepper_get_steps(&rl, &rr);

    int polls = 0;
    while (!stepper_steps_done())
    {
        // Always honour the stop condition first, even on this path: a real cliff
        // must halt instantly and be reported, never masked by no-progress logic.
        if (stop()) { stepper_halt(); return F_BATCH_STOP; }
        sleep_msec(2);
        polls++;
    }

    // Re-check the stop condition once after the batch settles: a cliff can latch
    // exactly as stepper_steps_done() flips, and a pinned/instant batch never
    // entered the poll loop at all (polls == 0) so it would otherwise skip stop().
    if (stop()) { stepper_halt(); return F_BATCH_STOP; }

    // Non-progress: a genuine MOVE_UNIT at SPEED_ULTRA_SLOW takes tens of ms, so the
    // poll loop runs >=1 iteration AND the readback showed the full step magnitude
    // pending. A dropped/pinned batch is instant-done (polls == 0) and showed ~0
    // pending. Either signal alone is sufficient; require both to be "real" to count
    // it as motion (conservative: any doubt -> treated as no-progress, never inflates).
    int abs_steps = steps < 0 ? -steps : steps;
    int pending   = (rl < 0 ? -rl : rl);   // left magnitude (left==right for forward)
    int moved_real = (polls > 0) && (pending >= abs_steps / 2);
    return moved_real ? F_BATCH_MOVED : F_BATCH_NOPROG;
}

int main(void)
{
    pynq_init();

    stepper_init();
    stepper_enable();

    switchbox_set_pin(IO_AR0, SWB_UART0_RX);
    switchbox_set_pin(IO_AR1, SWB_UART0_TX);

    // Set IIC0 switchbox pins BEFORE iic_init so the bus is valid for the
    // 0x70 mux probe in all_sensors_init() (parity with Motors/main.c).
    switchbox_set_pin(IO_AR_SCL, SWB_IIC0_SCL);
    switchbox_set_pin(IO_AR_SDA, SWB_IIC0_SDA);
    iic_init(IIC0);

    adc_init();   // thermistor (rock temperature) on ADC0

    bool sensors_initialised = all_sensors_init();
    if (!sensors_initialised) {
        printf("Error with sensor initialisation\n");
        pynq_destroy();
        return EXIT_FAILURE;
    }

    Cal cal = run_warmup();

    uart_init(UART0);
    uart_reset_fifos(UART0);

    sleep_msec(3000);

    int cal_loaded = cal_load();   // restore persisted CALBLACK calibration if present

    fprintf(stderr, "READY\n");
    send_message("LOG,READY");   // always wireless: key boot signal, independent of LOGON/LOGOFF
    if (cal_loaded)
    {
        send_message("LOG,Loaded saved clear calibration");
        exp_mon_start();                       // global cliff-stop active (calibrated)
        send_message("LOG,cliff monitor ACTIVE");
    }
    else
    {
        // do NOT auto-start: an uncalibrated monitor could read the floor as black
        // and block all forward motion. CALBLACK will calibrate and start it.
        send_message("LOG,Run CALBLACK - cliff monitor INACTIVE until calibrated");
    }

    char MSG[MAX_MSG_LEN];

    orientation_t ori =
    {
        .ort   = 1,
        .theta = 0.0f
    };

    // Initialise TCS3200 via module API: sets pin dirs + S0/S1.
    // Original inline init drove S0=HIGH, S1=LOW. Per TAOS datasheet Table 1 that
    // is the 20 % output setting, so we pass TCS3200_SCALING_20PCT — which drives
    // exactly S0=HIGH/S1=LOW. Boot GPIO levels are therefore byte-identical to the
    // old code; detect_black's calibrated thresholds were tuned at these levels and
    // must not change. (Replaces the former inline gpio_set_* block.)
    tcs3200_begin(S0, S1, S2, S3, SENSOR_OUT, TCS3200_SCALING_20PCT);

    uint16_t c, r, g, b;

    // =====================================================================
    // F1 AUTORUN — full autonomy + run-on-boot (manual §1.3, §3.2, §4.6)
    // After READY, auto-enter the EXPLORE mission with NO operator command.
    // The laptop only listens. A short pre-explore window lets an operator
    // drop to interactive command mode with a single wireless S/HOLD.
    //
    // GUARD: only auto-run if calibrated. cal_loaded (main.c:40) is 1 iff a
    // valid CALBLACK was restored; it also gates the cliff monitor. Uncalibrated
    // => monitor OFF => forward motion unsafe => skip autorun, fall through to
    // the command loop so the operator can run CALBLACK.
    // =====================================================================
    if (cal_loaded)
    {
        // Optional identification ping (F1 optional; coordinate with F8 — see notes).
        // Board id read from ~/robot_id at runtime so a single binary serves both boards.
        // Falls back to "41" if the file is missing or empty (safe default).
        {
            char robot_id[16] = "41";
            const char *home = getenv("HOME");
            if (!home) home = "/home/student";
            char id_path[128];
            snprintf(id_path, sizeof id_path, "%s/robot_id", home);
            FILE *id_f = fopen(id_path, "r");
            if (id_f)
            {
                char tmp[16];
                if (fgets(tmp, sizeof tmp, id_f))
                {
                    // strip trailing newline/whitespace
                    int tl = (int)strlen(tmp);
                    while (tl > 0 && (tmp[tl-1] == '\n' || tmp[tl-1] == '\r' || tmp[tl-1] == ' '))
                        tmp[--tl] = '\0';
                    if (tl > 0) snprintf(robot_id, sizeof robot_id, "%s", tmp);
                }
                fclose(id_f);
            }
            char hello_msg[32];
            snprintf(hello_msg, sizeof hello_msg, "HELLO,%s", robot_id);
            send_message(hello_msg);
        }
        send_message("LOG,AUTORUN: exploring in 5s - send S or HOLD to take manual control");

        // ---- soft-stop window: bounded, non-blocking poll for an early S/HOLD ----
        // ~5 s settle. NEVER use read_uart_message unguarded (it blocks on a
        // partial frame, main_header.h:157). Only read AFTER uart_has_data(); and
        // cap the whole window with a deadline so a malformed frame can't hang boot.
        const int   AUTORUN_WINDOW_MS = 5000;   // pre-explore settle + opt-out window
        const int   AUTORUN_POLL_MS   = 50;
        int         autorun_aborted   = 0;
        int         waited            = 0;

        while (waited < AUTORUN_WINDOW_MS)
        {
            if (uart_has_data(UART0))
            {
                // Bounded read: a real frame completes in ~1 ms; a partial/corrupt
                // frame returns 0 after at most this small budget instead of
                // blocking boot. Keep the budget << the window so a glitch can't
                // meaningfully stretch the ~5 s settle.
                if (autorun_read_bounded(MSG, 300)
                    && (strcmp(MSG, "S") == 0 || strcmp(MSG, "HOLD") == 0))
                {
                    autorun_aborted = 1;
                    break;
                }
                // any other early/partial frame: ignore, keep settling
            }
            sleep_msec(AUTORUN_POLL_MS);
            waited += AUTORUN_POLL_MS;
        }

        if (autorun_aborted)
        {
            g_stop = 0;   // don't carry the opt-out S into the first manual command
            send_message("LOG,AUTORUN cancelled - interactive command mode");
        }
        else
        {
            send_message("LOG,AUTORUN: entering EXPLORE (autonomous)");
            run_explore(&ori, &cal);          // self-contained: resets g_stop, starts monitor
            print_orientation(&ori);
            send_orientation(&ori);
            // run_explore returns only on operator S / trap give-up; then we
            // fall through to the command loop below for any manual follow-up.
            send_message("LOG,AUTORUN: EXPLORE returned - interactive command mode");
        }
    }
    else
    {
        // Uncalibrated: cliff monitor is OFF (main.c:54). Do NOT auto-explore.
        send_message("LOG,AUTORUN skipped - uncalibrated (run CALBLACK)");
    }
    // ===================== end F1 AUTORUN =====================

    while (1)
    {
        if (uart_has_data(UART0))
        {
            read_uart_message(UART0, MSG);

            log_msg("MSG = %s", MSG);

            // A freshly-issued command must not inherit a stale operator-stop. g_stop
            // latches (exp_check keeps returning STOP once S is seen) and was only
            // cleared inside run_explore, which silently disabled EXP1/SWEEPQ/ADV after
            // any earlier S-stop. Clear it here at dispatch (safe: a running command
            // polls UART itself; EXPLORE manages g_stop internally).
            g_stop = 0;

            // =========================
            // FORWARD UNTIL STOP
            // =========================
            if(strcmp(MSG, "F") == 0)
            {
                // Last-resort cap on forward travel in MOVE_UNIT chunks. Raised ABOVE
                // the arena diagonal (~212 cm / 6.15 cm-per-unit ≈ 35 chunks -> 40) so a
                // legitimate full-arena straight traverse is never truncated. With count
                // now counting ONLY real-motion batches (f_batch_forward == F_BATCH_MOVED),
                // a cap hit here represents a TRUE distance, so STEPS,count is valid.
#define F_MAX_CHUNKS 40
                // Consecutive no-progress batches that mean "the robot is pinned and not
                // advancing" (dropped/instant-done batches). A single instant batch can
                // happen transiently; require K in a row before declaring non-progress.
#define F_NOPROG_LIMIT 3

                // count = MOVE_UNIT chunks of REAL motion completed (matches
                // advance_monitored; UI scales by CM_PER_UNIT to centimetres).
                // Incremented ONLY on F_BATCH_MOVED, so a pinned-on-tape F that never
                // actually advances emits the truthful STEPS,0 (not the old bogus 30).
                long count   = 0;
                int  noprog  = 0;   // consecutive no-progress batches

                while(1)
                {
                    // Last-resort cap (true distance now that count is motion-only).
                    if (count >= F_MAX_CHUNKS)
                    {
                        log_msg("F: max chunks (%d) reached", F_MAX_CHUNKS);
                        { char stp[64]; sprintf(stp, "STEPS,%ld", count); send_message(stp); }
                        print_orientation(&ori);
                        send_orientation(&ori);
                        break;
                    }

                    // one batch at a time (no queue-ahead). f_batch_forward STILL checks
                    // the stop condition on every path, so a cliff (g_black) or "S" halts
                    // and reports even on a dropped/instant batch — a real cliff is never
                    // missed by the no-progress logic.
                    int r = f_batch_forward(MOVE_UNIT, SPEED_ULTRA_SLOW, stop_black_or_S);

                    if (r == F_BATCH_STOP)
                    {
                        if (g_black)
                        {
                            log_msg("BLACK DETECTED");
                            { char stp[64]; sprintf(stp, "STEPS,%ld", count); send_message(stp); }
                            report_nogo();   // UI: red cliff box at the halt pose
                            print_orientation(&ori);
                            send_orientation(&ori);
                            g_black_ack();
                            break;
                        }
                        char stp[64];
                        sprintf(stp, "STEPS,%ld", count);
                        send_message(stp);
                        log_msg("NEW MSG = S");
                        print_orientation(&ori);
                        send_orientation(&ori);
                        break;
                    }

                    if (r == F_BATCH_NOPROG)
                    {
                        // Batch did no motion. Count consecutive no-progress events; a
                        // run of them means the robot is pinned (e.g. nose on tape) and
                        // can't advance — break instead of spinning. count stays truthful.
                        if (++noprog >= F_NOPROG_LIMIT)
                        {
                            log_msg("F: non-progress (%d consecutive no-motion batches), halting (count=%ld)", noprog, count);
                            { char stp[64]; sprintf(stp, "STEPS,%ld", count); send_message(stp); }
                            // If pinned on real black, take the SAME path as a black stop:
                            // NOGO box + ack the latch. Otherwise just report progress.
                            if (g_black)
                            {
                                report_nogo();   // UI: red cliff box at the halt pose
                                print_orientation(&ori);
                                send_orientation(&ori);
                                g_black_ack();
                            }
                            else
                            {
                                print_orientation(&ori);
                                send_orientation(&ori);
                            }
                            break;
                        }
                        // transient instant batch: retry without inflating count
                        continue;
                    }

                    // r == F_BATCH_MOVED: one real MOVE_UNIT of progress confirmed.
                    count++;
                    noprog = 0;   // real motion clears the no-progress streak
                }
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

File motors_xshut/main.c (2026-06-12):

#include "main_header.h"
#include "shuffle.h"

struct rock_data_t {
	enum e_rock_color color;
	int32_t size;
	float temp;
};

int main(void)
{
    pynq_init();

    stepper_init();
    stepper_enable();

    switchbox_set_pin(IO_AR0, SWB_UART0_RX);
    switchbox_set_pin(IO_AR1, SWB_UART0_TX);

    iic_init(IIC0);

    bool sensors_initialised = all_sensors_init();
    if (!sensors_initialised) {
        printf("Error with sensor initialisation\n");
        pynq_destroy();
        return EXIT_FAILURE;
    }

    Cal cal = run_warmup();

    uart_init(UART0);
    uart_reset_fifos(UART0);

    sleep_msec(3000);

    fprintf(stderr, "READY\n");

    char MSG[MAX_MSG_LEN];

    orientation_t ori =
    {
        .ort   = 1,
        .theta = 0.0f
    };

    gpio_set_direction(S0, GPIO_DIR_OUTPUT);
    gpio_set_direction(S1, GPIO_DIR_OUTPUT);
    gpio_set_direction(S2, GPIO_DIR_OUTPUT);
    gpio_set_direction(S3, GPIO_DIR_OUTPUT);

    gpio_set_direction(SENSOR_OUT, GPIO_DIR_INPUT);

    gpio_set_level(S0, GPIO_LEVEL_HIGH);
    gpio_set_level(S1, GPIO_LEVEL_LOW);

    uint16_t c, r, g, b;

    while (1)
    {
        if (uart_has_data(UART0))
        {
            read_uart_message(UART0, MSG);

            fprintf(stderr, "MSG = %s\n", MSG);

            // =========================
            // FORWARD UNTIL STOP
            // =========================
            if(strcmp(MSG, "F") == 0)
            {
                long count = 0;

                while(1)
                {
                    move_forward(MOVE_UNIT, SPEED_MEDIUM);

                    count++;

                    wait_motion(100);

                    if(uart_has_data(UART0))
                    {
                        read_uart_message(UART0, MSG);

                        fprintf(stderr, "NEW MSG = %s\n", MSG);

                        if(strcmp(MSG, "S") == 0)
                        {
                            char stp[64];

                            sprintf(stp, "STEPS,%ld", count);

                            send_message(stp);

                            fprintf(stderr, "%s\n", stp);

                            print_orientation(&ori);

                            send_orientation(&ori);

                            break;
                        }
                    }
                }
            }

            // =========================
            // FORWARD UNTIL BLOCK
            // =========================
             else if(strcmp(MSG, "FB") == 0)
             {
		 // turn_degree_other_way();

		 read_distance_forward();

                 long count = 0;

                 while(1)
                 {
                     int32_t dist = read_distance_forward();

                     if(dist >= 0 && dist <= 50)
                     {
                         // char stp[64];
                         // sprintf(stp, "STEPS,%ld", count);
                         // send_message(stp);
                         // fprintf(stderr, "%s\n", stp);
                         print_orientation(&ori);
                         send_orientation(&ori);
                         break;
                     }

                     move_forward(MOVE_UNIT, SPEED_ULTRA_SLOW);
                     wait_motion(3000);
                     count++;

                    if(uart_has_data(UART0))
                    {
                        read_uart_message(UART0, MSG);

			if(strcmp(MSG, "S") == 0)
                        {
                        char stp[64];
                        
                        sprintf(stp, "STEPS,%ld", count);
                        
                        send_message(stp);
                        
                        fprintf(stderr, "%s\n", stp);
                        
                        print_orientation(&ori);
                        
                        send_orientation(&ori);
                        
                        break;
                        }


                        // if(strcmp(MSG, "S") == 0)
                        // {
                        //     send_orientation(&ori);

                        //     char stp[64];
                        //     sprintf(stp, "STEPS,%ld", count);
			// 	send_message(stp);
                        //     break;
                        // }
                    }

                 }
             }

            // =========================
            // MOVE X,Y
            // =========================
            else if (strncmp(MSG, "MOVE", 4) == 0)
            {
                int x, y;

                if (sscanf(MSG, "MOVE,%d,%d", &x, &y) == 2)
                {
                    fprintf(stderr, "X = %d\n", x);
                    fprintf(stderr, "Y = %d\n", y);

                    if (x > 0)
                    {
                        move_forward(x * MOVE_UNIT, SPEED_FAST);

                        wait_motion(2000);
                    }

                    if (x < 0)
                    {
                        turn_180();

                        wait_motion(2000);

                        rotate_orientation(&ori, 180.0f);

                        ori.theta = 0.0f;

                        print_orientation(&ori);

                        send_orientation(&ori);

                        move_forward((-x) * MOVE_UNIT, SPEED_FAST);

                        wait_motion(2000);
                    }

                    if (y > 0)
                    {
                        turn_right_90();

                        wait_motion(2000);

                        rotate_orientation(&ori, 90.0f);

                        ori.theta = 0.0f;

                        print_orientation(&ori);

                        send_orientation(&ori);
                    }
                    else if (y < 0)
                    {
                        turn_left_90();

                        wait_motion(2000);

                        rotate_orientation(&ori, -90.0f);

                        ori.theta = 0.0f;

                        y = -y;

                        print_orientation(&ori);

                        send_orientation(&ori);
                    }

                    if (y != 0)
                    {
                        move_forward(y * MOVE_UNIT, SPEED_FAST);

                        wait_motion(2000);
                    }

                    fprintf(stderr, "MOVE COMPLETE\n");

                    print_orientation(&ori);

                    send_orientation(&ori);
                }
            }

            // =========================
            // TURN 180
            // =========================
            else if(strcmp(MSG, "U") == 0)
            {
                turn_180();

                wait_motion(100);

                rotate_orientation(&ori, 180.0f);

                ori.theta = 0.0f;

                print_orientation(&ori);

                send_orientation(&ori);
            }
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

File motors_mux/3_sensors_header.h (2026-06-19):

#pragma once
#include <libpynq.h>
#include <stdio.h>
#include <stdlib.h>
#include <stdint.h>
#include <stdbool.h>
#include <math.h>

/* ─── Temperature (thermistor on ADC0) ──────────────────────────────────── */
// From Venus/individual_sensors/temperature.c: ADC voltage divider -> resistance
// -> Steinhart-Hart -> degrees C. Requires adc_init() at startup.
#define TEMP_INVALID  (-100.0f)   // sentinel: no valid reading

static int r_to_t(double r_t)
{
    const double A = 0.0007984;
    const double B = 0.0002664;
    const double C = 0.00000013009;
    double lnR = log(r_t * 1000);
    double t = 1.0 / (A + B * lnR + C * lnR * lnR * lnR);
    return (int)(t - 273.15);
}

// Average a few ADC samples; returns degrees C, or TEMP_INVALID if no usable read.
static float read_temperature(void)
{
    const double v_ref = 3.3, R2 = 0.33;
    double sum = 0.0;
    int n = 0;
    for (int i = 0; i < 8; i++)
    {
        double v_out = adc_read_channel(ADC0);
        if (v_out > 0.05 && v_out < v_ref)          // guard div-by-zero / rail
        {
            double r_t = (v_ref - v_out) * (R2 / v_out);
            int t = r_to_t(r_t);
            if (t > -20 && t < 120) { sum += t; n++; }   // drop implausible
        }
        sleep_msec(5);
    }
    return (n > 0) ? (float)(sum / n) : TEMP_INVALID;
}

/* ─── Distance sensors ──────────────────────────────────────────────────── */
#define SYSRANGE_START        0x00
#define XSHUT_PIN_1           IO_AR10
#define XSHUT_PIN_2           IO_AR9
#define CALIBRATION_OFFSET_MM -27
#define DEFAULT_ADDRESS       0x29
#define SENSOR1_ADDRESS       0x30
#define SENSOR2_ADDRESS       0x31
#define REG_ADDR_CONFIG       0x8A
#define MAX_RETRIES           10
#define RETRY_DELAY_MS        200

/* ─── Dual-backend globals (XSHUT vs PCA9548A mux) ─────────────────────── */
// Resolved ONCE in all_sensors_init(); zero per-read overhead beyond the
// mux's own channel-select write. PCA9548A_ADDR / SENSOR_ADDR / TCS_REG_*
// / VL53_REG_ID are defined in main_header.h BEFORE this file is included,
// so they are visible here.
enum { BACKEND_XSHUT = 0, BACKEND_MUX = 1 };
static int g_sensor_backend = BACKEND_XSHUT;

// Mux channel assignments. -1 = not found / not applicable (XSHUT path).
static int g_ch_forward  = -1;   // forward VL53 mux channel
static int g_ch_overhead = -1;   // overhead VL53 mux channel
static int g_ch_color    = -1;   // TCS34725 mux channel

// Probe one byte from an I2C address: returns 0 (ACK) or nonzero (NAK/error).
// Used to detect the mux at boot.
static int mux_probe(uint8_t addr)
{
    uint8_t dummy = 0;
    return iic_read_register(IIC0, addr, 0x00, &dummy, 1);
}

// Select a single mux channel (write 1<<ch to the mux control register).
// Returns 0 on success, nonzero on I2C error.
static int mux_select_channel(uint8_t ch)
{
    uint8_t mux_state = (uint8_t)(1u << ch);
    return iic_write_register(IIC0, PCA9548A_ADDR, 0x00, &mux_state, 1);
}

// Scan all 8 mux channels, probing for TCS34725 (color) and VL53L0X (distance).
// Forward role = lower-numbered VL53 channel; overhead = higher.
// Writes results into *vl_lo, *vl_hi, *col (-1 = not found).
static void mux_scan_vl53_color(int *vl_lo, int *vl_hi, int *col)
{
    *vl_lo = -1; *vl_hi = -1; *col = -1;
    int vl53_found = 0;   // count of VL53s seen so far

    for (int ch = 0; ch < 8; ch++)
    {
        if (mux_select_channel((uint8_t)ch) != 0)
            continue;   // channel select failed; skip
        sleep_msec(10);

        uint8_t id = 0;

        // Probe for TCS34725 color sensor
        if (*col < 0 &&
            iic_read_register(IIC0, SENSOR_ADDR, TCS_REG_ID, &id, 1) == 0)
        {
            if (id == 0x44 || id == 0x4D)
            {
                *col = ch;
                printf("MUX scan: TCS34725 (color) ch%d ID=0x%02X\n", ch, id);
            }
        }

        // Probe for VL53L0X distance sensor
        id = 0;
        if (iic_read_register(IIC0, SENSOR_ADDR, VL53_REG_ID, &id, 1) == 0)
        {
            if (id == 0xEE)
            {
                if (vl53_found == 0) { *vl_lo = ch; }
                else if (vl53_found == 1) { *vl_hi = ch; }
                printf("MUX scan: VL53L0X #%d ch%d ID=0x%02X\n", vl53_found + 1, ch, id);
                vl53_found++;
            }
        }
    }

    // Deselect all channels
    uint8_t off = 0;
    iic_write_register(IIC0, PCA9548A_ADDR, 0x00, &off, 1);

    printf("MUX scan result: vl_lo(fwd)=ch%d  vl_hi(oh)=ch%d  color=ch%d\n",
           *vl_lo, *vl_hi, *col);
}

// Shared VL53L0X transport: trigger → wait → read 0x1E → clear interrupt.
// MUX path: selects ch first (SENSOR_ADDR 0x29); XSHUT path: uses addr directly.
// Returns raw distance in mm, or -1 on any I2C error.
static int32_t vl53_read_raw_mm(uint8_t addr, int ch)
{
    if (g_sensor_backend == BACKEND_MUX)
    {
        if (ch < 0) return -1;
        if (mux_select_channel((uint8_t)ch) != 0) return -1;
        addr = SENSOR_ADDR;   // all mux sensors share 0x29
    }

    uint8_t trig = 0x01;
    if (iic_write_register(IIC0, addr, 0x00, &trig, 1)) return -1;

    // MUX sensors need a slightly longer settle (60 ms per Motors/ reference);
    // XSHUT sensors are fine at 30 ms (existing behaviour preserved).
    sleep_msec((g_sensor_backend == BACKEND_MUX) ? 60 : 30);

    uint8_t data[2];
    if (iic_read_register(IIC0, addr, 0x1E, data, 2)) return -1;

    int32_t raw = (int32_t)((data[0] << 8) | data[1]);

    // Clear interrupt flag
    uint8_t clr = 0x01;
    iic_write_register(IIC0, addr, 0x0B, &clr, 1);

    return raw;
}

// #define INTER_READING_DELAY_DIST_FORW_MS 5
// #define INTER_READING_DELAY_DIST_OVERH_MS 40

// #define SENSOR_TIMEOUT_MS 100

#define MAX_FORWARD_DELTA_MM 100

#define MAX_RANGE_MM 500 // For the forward dist sensor
#define MAX_OVERHEAD_RANGE_MM 90

/* ─── TCS34725 registers ────────────────────────────────────────────────── */
#define TCS_ADDR    0x29
#define REG_ENABLE  0x80
#define REG_ATIME   0x81
#define REG_WTIME   0x83
#define REG_CONTROL 0x8F
#define REG_ID      0x92
#define REG_CDATAL  0x94

/* ─── Color sensor settings ─────────────────────────────────────────────── */
#define ATIME   0x00
#define WTIME   0xFF
#define GAIN    0x00

#define WARMUP_SAMPLES  8
#define WHITE_FACTOR    7.00f
#define BLACK_FACTOR    0.10f

#define LUX_R  (-0.32466f)
#define LUX_G  ( 1.57837f)
#define LUX_B  (-0.73191f)

typedef struct {
    float lux;
    int r, g, b;
    bool valid;
} ColorReading;

/* ─── Calibration state ─────────────────────────────────────────────────── */
typedef struct {
    float r_white_ratio;
    float g_white_ratio;
    float b_white_ratio;
    float clear_white;
    float clear_black;
} Cal;
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

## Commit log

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2026-05-13 Add files via upload
    Sensor mount design
    [Draft 1.SLDPRT]
2026-05-29 Add files via upload
    Header including movment functions, black tape functions, and distance sensor functions
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2026-06-04 Preliminary integration of motors code with 3 sensors (all except analog color)
2026-06-08 Update and rename UI_code to UI_code.py
    Visual upgrade + mountain tracking sweep added
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2026-06-15 Add motors_newest: 180° symmetric sweep, EXPLORE command, UI mapping viz
    Snapshot of the already-built/deployed work that preceded wireless logging:
    - 180° symmetric object sweep + O no-object guard
    - explore.h: queueing sweep, monitored approach/advance, return-to-origin,
    rock/mountain classify, black-monitor pthread, EXPLORE loop + test sub-commands
    - UI_code.py: REGION / MOUNTAIN / NOGO handlers and draw helpers
2026-06-15 Add wireless terminal logging over MQTT (testing tool)
    Route important console logs to the laptop UI via the existing send_message
    (UART -> pynqbridge -> MQTT) path, so testing no longer needs an SSH cable.
    - main_header.h: log_msg() helper (dual stderr + LOG,<text> over MQTT), gated by
    runtime g_log_wireless flag (default ON for testing).
    - READY is sent wirelessly unconditionally (key boot signal).
    - Converted important logs (MSG, MOVE, BLACK DETECTED, OBJECT DETECTED, SWEEP
    COMPLETE, classification, EXPLORE start/done, UNKNOWN COMMAND) to log_msg.
    - Excluded high-frequency spam (per-read R=G=B, per-degree DIST, FWD/OH polls,
    distance-sensor OUT OF RANGE) to avoid flooding the link.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
    [explore.h, main.c, main_header.h]
2026-06-15 Add dynamic TCS3200 black calibration (CALBLACK / CALRESET)
    Runtime, session-scoped recalibration of the downward black sensor so it works
    across lighting conditions, replacing the fixed compile-time RED/GREEN/BLUE
    MIN/MAX constants.
    - main_header.h: per-channel cal_min/cal_max + cal_black_thresh globals (seeded
    from the defaults); detect_black reads them; read_channel_raw / read_channel_refs
    helpers (average pulse width, drop pulseIn timeouts).
    - main.c: CALBLACK guides the user via wireless LOG with timed prompts -- show
    WHITE (floor) 5s, switch 3s, show BLACK (tape) 5s -- samples each R/G/B channel,
    validates contrast (aborts + keeps old cal on failure / div-by-zero guard), and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
    [main.c, main_header.h]
2026-06-15 Use TCS3200 clear channel for black detection (clear-only)
    Black is a luminance property, so the unfiltered CLEAR photodiode (S2=H,S3=L) is
    the most direct, highest-SNR signal. detect_black now reads CLEAR only (1 read vs
    3) -> the black-monitor thread polls ~3x faster, so the robot stops sooner after
    the ahead-of-wheels down sensor hits tape (cliff-safety gain).
    - main_header.h: read_channel_raw gains the CLEAR case; cal arrays widened to 4
    (index 3=CLEAR) with provisional CLEAR_MIN/MAX; detect_black is clear-only and
    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
2026-06-15 Fix queued-step overshoot: halt steppers on stop conditions
    stepper_steps() is non-blocking and holds a current + one queued command, so the
    forward-until-X loops (which fired a new MOVE_UNIT on a fixed timer) left steps
    running when they broke -> the robot kept moving after black/obstacle was detected
    (seen on STOPBLACK at SPEED_ULTRA_SLOW).
    - main_header.h: stepper_halt() (stepper_reset + re-enable) cancels in-flight +
    queued steps; move_batch_until() polls a batch to completion and halts the instant
    a stop fn fires (also prevents queue-ahead); stop_on_fwd_block / stop_on_uart_S.
    - main.c: STOPBLACK (also syncs SPEED_ULTRA_SLOW), F, FB, O now move via
    move_batch_until and stepper_ha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
    [explore.h, main.c, main_header.h]
2026-06-17 Persist CALBLACK calibration across reboots
    CALBLACK previously only set runtime globals, lost on power-cycle. Now it writes
    the calibrated CLEAR channel to /home/student/calblack.cfg and the firmware loads
    it at boot.
    - main_header.h: CAL_FILE + cal_save / cal_load (validates min<max, both>0) /
    cal_forget. Compile-time #defines remain the immutable original.
    - main.c: boot calls cal_load (READY hint reflects loaded-vs-defaults); CALBLACK
    success calls cal_save; CALRESET calls cal_forget so reboot reverts to defaults.
    [main.c, main_header.h]
2026-06-17 Make the black monitor a global cliff-stop
    The MON thread set g_black but only EXPLORE polled it, so manual F drove over tape.
    Now the monitor is the single owner of the TCS3200 and every forward-translating
    command halts on g_black.
    - Boot: auto-start the monitor ONLY if a saved calibration loaded (an uncalibrated
    monitor could read the floor as black and block all motion); else warn INACTIVE
    until CALBLACK.
    - explore.h: stop_black_or_S, g_black_ack; run_explore no longer stops the monitor
    on exit (stays active globally).
    - main.c: F / FB / O / MOVE (fwd legs) / R / L halt on g_black (or S) via
    move_batch_until + ack; STOPBLACK and CLIFFCHK pause+restore the monitor and read
    the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
    [explore.h, main.c, main_header.h]
2026-06-17 Revert heading_update to silent (drop heading_update_tracked)
    heading_update() corrects physical wheel drift back to the intended heading using
    the static object as the bearing reference; by design it must NOT touch ori (that
    keeps ori in sync with the corrected heading). The EXPLORE-era heading_update_tracked
    double-counted the correction, shifting ori by the drift each cycle and degrading
    return_to_origin.
    - explore.h: delete heading_update_tracked; approach_object uses the silent
    heading_update() (ori now unused there -> (void)ori).
    - main.c: HU2 calls heading_update() and keeps before/after prints as an
    ori-unchanged check.
    [explore.h, main.c]
2026-06-17 Fix SWEEPQ (increment 1): blocking in-place 180deg sweep; silence CLR spam
    SWEEPQ turned ~90 not 180 and missed in-range rocks. Causes: (a) the global cliff
    monitor's g_black aborted sweep_collect mid-sweep, masked as OBJN,0; (b) non-blocking
    turn_degree fired faster than the slow steps completed -> step loss; (c) turn_degree
    is an arc (both wheels fwd), not in-place.
    - main_header.h: comment out the per-call CLR= print (monitor was flooding console).
    - explore.h: new sweep_rotate() — blocking (polls stepper_steps_done), in-place
    (stepper_steps(-s,+s)), settle before sampling. sweep_collect rebuilt on it over a
    true 180 deg in SWEEP_STEP_DEG (1 deg, tunable) increments, sampling settl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
    [explore.h, main.c, main_header.h]
2026-06-17 SWEEPQ detection (increment 2): raw reads + persistence + distance segmentation
    4-rock test returned only 2 objects + many REJECTED readings. Causes: the forward
    reader's delta-rejection (>100mm jump -> -1) dropped legit pans across rocks at
    different ranges, and contiguous-in-range clustering merged overlapping-cone rocks
    keeping only the min distance.
    - 3_sensors_header.h: add read_distance_forward_raw() (no delta-reject / no last_valid);
    the delta-reject reader stays for FB/O/STOPBLACK.
    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
2026-06-17 UI: plot SWEEPQ-detected objects with distance labels
    Add OBJN/OBJ handlers (were ignored). OBJN clears the previous sweep's markers;
    each OBJ,rel,dist is placed relative to the robot (angle = robot heading + rel,
    dist = dist_mm/10 + SENSOR_OFFSET_CM) reusing the SCAN placement math. Draws a
    green object dot + a line from the robot + a '<dist> cm' label, and a [SWEEP]
    findings entry. Markers tracked in self.sweep_items and cleared each sweep.
2026-06-17 Harden overhead classification + cap O approach (sensor robustness)
    Overhead sampling could hang and miscompute size:
    - classify_object/O looped 'continue' forever on persistent overhead disconnect
    ({-1,false}); EXP1/O/EXPLORE would wedge.
    - out-of-range overhead ({-1,true}) was averaged as -1, dragging size down.
    Fixes:
    - explore.h classify_object: bound attempts (EXP_OH_MAX_ATTEMPTS); average ONLY
    valid (>=0) distances; keep out-of-range as the tall/black-rock signal via
    flag_black (not as -1); return -3 'overhead sensor error' if unusable; fall back
    to size 6 when all readings are out-of-range. New EXP_OH_* constants.
    - main.c O: replace the duplicate inline color+overhead+binnin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
    [explore.h, main.c]
2026-06-17 Add ALGORITHM.md: living system/algorithm overview for newcomers
    Describes the PYNQ explore-and-map robot end to end: hardware/comms, sensors,
    motion/stepper conventions, calibration, the global cliff-stop, the EXPLORE loop,
    sweep object detection, classification, the UI, commands + message protocol, and
    known limitations. Has a MAINTENANCE header: keep it current as firmware/UI
    functionality changes.
2026-06-17 Fix stale latched flags disabling commands (g_stop + g_black)
    g_stop latched (set by exp_check on S, cleared only in run_explore) so any
    EXP1/SWEEPQ/ADV after an earlier S-stop silently no-op'd. g_black is the same
    class (sticky-set by the monitor, never self-cleared); EXP1/ADV neither acked nor
    cleared it -> stale-disabled too.
    - main.c: reset g_stop=0 at command dispatch (fixes the whole g_stop class).
    - main.c: g_black_ack() at entry of EXP1 and ADV (mirrors SWEEPQ) so a stale cliff
    latch doesn't block them; the slow approach + always-on monitor re-assert a real
    cliff within sub-mm. NOT cleared globally at dispatch -> fast MOVE/R/L keep the
    airtight cliff-stop (they already self-he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
    [main.c]
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2026-06-17 O and FB reuse approach_object (two-phase creep everywhere)
    Both O and FB had stale inline approach loops (O even hardcoded dist<=50). Replace
    both with the shared approach_object so they get the two-phase coarse(40)->fine
    creep(25), the cap, consistent thresholds, and cliff/stop handling; removes the
    drifted duplicates (one approach path: EXP1/EXPLORE/O/FB).
    - O: approach_object then existing classify; ADV_BLACK/ADV_STOP logged+skip.
    - FB: approach_object; ADV_BLACK -> log + g_black_ack (preserves its self-heal).
    - Both report STEPS,moved.
    - ADV/STOPBLACK/avoid_mountain unchanged (not approach-to-target).
    - ALGORITHM.md: note the shared approach.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
    [main.c]
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2026-06-17 Unify all motion speeds to SPEED_ULTRA_SLOW (keep ULTRA_ULTRA fine creep)
    Part A: replace every SPEED_FAST/MEDIUM/SLOW/TURN usage with SPEED_ULTRA_SLOW
    (MOVE legs, R/L nudges, RET, turn_left/right_90, turn_180, exp_rotate_deg,
    return_to_origin, advance_monitored, handle_black/avoid_mountain back-offs).
    Kept SPEED_ULTRA_ULTRA_SLOW (approach phase-2 creep) and the asymmetric
    turn_degree/turn_minute literals (30000/15000).
    Part B (required): the fixed wait_motion() delays after turns/moves were sized for
    the faster speeds and are too short at ULTRA_SLOW. Added wait_steps_done() (poll
    stepper_steps_done + caster settle) and made move_forward + turn_left/right_90 +
    turn_180 block to completion;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
    [explore.h, main.c, main_header.h]
2026-06-17 Restore frequent heading updates in approach (smaller phase-1 step)
    The overshoot fix replaced O's 'move_forward(MOVE_UNIT)+wait_motion(4000)' with a
    blocking move_batch_until(MOVE_UNIT), so heading_update only ran after a FULL move
    unit instead of the old ~4s timer (which fired partway through a unit at ultra-slow).
    That ~doubled the distance between heading updates and hurt tracking.
    Fix: phase-1 of approach_object now steps EXP_APPROACH_STEP (200, < MOVE_UNIT 500)
    per heading_update -> re-aims ~as often as before, while keeping the blocking
    batch that fixed the overshoot. Bumped EXP_APPROACH_CAP 20->40 (smaller steps).
    Shared by EXP1/EXPLORE/O/FB.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
    [explore.h]
2026-06-17 Final-stop tuning: creep to 15mm at slowest speed + manual 5mm nudge
    approach_object phase 2 (shared by EXP1/EXPLORE/O/FB):
    - EXP_APPROACH_FINAL_MM 25->15 (forward sensor reliable to ~here).
    - SPEED_ULTRA_ULTRA_SLOW 60000->65535 (slowest possible).
    - After confirming the 15mm stop, do a fixed open-loop forward nudge of
    EXP_FINAL_NUDGE_STEPS (~40 steps ~= EXP_FINAL_NUDGE_MM 5mm via EXP_MM_PER_UNIT)
    so the overhead parks over the rock; dead-reckoned because the VL53L0X is
    unreliable below ~15mm. Nudge halts on a cliff (new stop_on_gblack) and is
    skipped if the 15mm stop was never confirmed (object lost / cap).
    - ALGORITHM.md updated.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
    [explore.h, main_header.h]
2026-06-17 Revert sweep_right_for_object (RSWEEP/O) to original ~90deg sweep
    Restore the pre-first-commit sweep used by RSWEEP and O: single-direction
    turn_degree scan from current heading, stop on object (dist<400) or at
    ori->theta>=89. Undoes the 180deg symmetric variant. The EXPLORE queueing
    sweep (sweep_collect) is separate and unchanged.
    [main_header.h]
2026-06-17 RET/return_to_origin: reverse straight back instead of about-face (less drift)
    return_to_origin did turn_180 + drive-forward + heading-trim; the 180 turn's angle
    error skewed the whole return path -> lateral drift (seen in RET,3). Now it drives
    straight in REVERSE the same distance (heading unchanged, path retraced), then a
    single rotation restores the scan-center heading at the origin (delta=0 for RET, so
    no turn at all). Only straight-line slip remains.
    Note: shuffle recalibration (the separate sideways-motion idea) intentionally NOT
    done here - the shuffle data doesn't apply to RET's forward/turn drift.
    [explore.h]
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2026-06-17 RSWEEP: use raw forward reader so it stops immediately on a cube
    sweep_right_for_object called read_distance_forward (delta-reject): a panning
    sweep makes the distance jump suddenly onto a cube, which the >100mm-jump filter
    REJECTED (-> -1), so dist<400 never tripped and the robot kept turning past it
    (worse, the reject path doesn't update last_valid, so it kept rejecting). Switch
    the sweep to read_distance_forward_raw() (no delta-reject) like the EXPLORE sweep
    - big jumps are real during a pan. Approach/FB/O keep the delta-reject reader.
    (flag_black is the overhead sensor's field, unrelated to RSWEEP.)
    [main_header.h]
2026-06-17 Turns: revert in-place rotations to SPEED_TURN (fix ~216deg overshoot)
    The 'all speeds -> SPEED_ULTRA_SLOW' change broke turns: TURN_90_STEPS=800 /
    TURN_180_STEPS=1500 are empirically calibrated at SPEED_TURN, where wheel slip
    absorbs part of each turn. At SPEED_ULTRA_SLOW the wheels grip fully (no slip), so
    the same step counts over-rotate (~216deg for '180', matching the reported 180+30/45).
    Confirmed: motors_xshut turn_180 used SPEED_TURN with identical step counts and was
    accurate. Reverted turn_left_90/turn_right_90/turn_180 + exp_rotate_deg to SPEED_TURN
    (rotations don't translate, so cliff-safety is unaffected); forward motion stays slow.
    Sibling left for verification: sweep_rotate a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
    [explore.h, main_header.h]
2026-06-17 Turns: SPEED_ULTRA_SLOW with no-slip-recalibrated step counts (exact 180/90)
    At SPEED_ULTRA_SLOW there's no wheel slip, so the SPEED_TURN-era counts (800/1500)
    over-rotate ~1.2x (1500 -> ~216 deg). Recalculated for the no-slip regime:
    TURN_180_STEPS_US=1250, TURN_90_STEPS_US=625 (1500*180/216; cross-checks with track
    12.5 cm, cm/step=pi*8/1600). turn_left_90/turn_right_90/turn_180 + exp_rotate_deg now
    run at SPEED_ULTRA_SLOW with the *_US counts (deterministic). sweep_rotate (SWEEPQ)
    left untouched - still TURN_90_STEPS @ ULTRA_SLOW, slightly over-covering by design.
    1250/625 are calculated from an eyeballed ~216; fine-tune via a U test:
    new_180 = round(1250*180/observed).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
    [explore.h, main_header.h]
2026-06-17 Docs: add thermistor/temperature to ALGORITHM.md (sensors + classification)
    Temperature feature was implemented (read_temperature on ADC0, classify_object
    fills temp, FOUND_ROCK carries it, TEMP command loops, UI shows it) but the doc
    didn't mention the thermistor. Add it to the sensor list and the classification
    section.
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2026-06-17 Turn calibration: unify all turns (incl. SWEEPQ) on TURN_180_STEPS_US=1280
    - TURN_180_STEPS_US 1406->1280, TURN_90_STEPS_US 703->640 (validated no-slip
    at SPEED_ULTRA_SLOW).
    - sweep_rotate (SWEEPQ) now derives steps/deg from TURN_180_STEPS_US/180
    instead of the old TURN_90_STEPS=800, and accumulates the fractional step
    (g_sweep_residual, reset per sweep) so the 0.5deg increments don't drift:
    the sweep covers exactly 180deg, returns to origin, and rel_deg matches
    physical heading.
    - Remove the now-dead TURN_90_STEPS=800 / TURN_180_STEPS=1500 defines; there
    is now one turn calibration.
    - ALGORITHM.md updated to match.
    [explore.h, main_header.h]
2026-06-18 Integrate F3+F1+F4+F5+F8 reconciliation batch
    Lands the reconciliation contract (reconciliation-F1-F3-F4-F5-F8) as one
    integrated change set. HW-test gate removed per user request.
    - F3 trap-escape (was uncommitted): EXP_TRAP_* + escape_trap/escape_scan,
    haz streak; run_explore/advance_with_escape rewrite. BUG-2 (mountain
    strafe not cliff-gated) left UNFIXED, still flagged.
    - F1 autonomy/boot: main.c AUTORUN before while(1), gated on cal_loaded,
    ~5s bounded soft-stop window (non-blocking UART read); student-startup.sh.
    - F4 POSFIX: least-squares translation in resweep_correct, emits
    POSFIX,dx,dy on RSC alongside DRIFT/DOBJ; UI POSFIX handler.
    - F5 BLACKPT: handle_black emits BLACKPT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
    [explore.h, main.c]
2026-06-18 Apply coordinator-audit fixes (must + should-fix, items 1-10)
    Adversarial audit (workflow wjc80blfo) of af58604 found a blocker + several
    real defects. Fixes (BUG-2 class deferred):
    - F4 POSFIX sign inversion: negate dx/dy at emit so a rightward drift emits
    +D, matching the UI transform (marker was correcting the wrong way).
    - F4 re-swept bearings: subtract heading drift before the translation calc
    so rotation doesn't pollute the position fix.
    - F1 soft-stop window: new bounded autorun_read_bounded() replaces the
    unguarded read_uart_message (busy-waits per byte) so a partial/corrupt
    frame can't hang unattended boot past the deadline.
    - F1 HELLO id: read board id from ~/robot_id (fal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
    [explore.h, main.c]
2026-06-18 Push: F2 coverage + UI-feedback parity + BUG-2 cliff-gate (audited)
    Ultra-accelerated parallel push (5 proposers -> serialized integration ->
    adversarial audit wvt3v6gru -> fixes). All single-robot features up to
    coordination, driven to a testable state. Builds clean on-device; NOT pushed.
    BUG-2 cliff-gate (reverses earlier defer, user-approved):
    - shuffle.h: steps_blocking/shuffle_step_*/shuffle_sideways now return int and
    poll g_black; halt+abort the strafe on black. Stale latch cleared at
    shuffle_sideways entry. Gate at the primitive covers avoid_mountain + SHL/SHR/MTN.
    - main.c SHL/SHR: g_black_ack() on aborted strafe. shuffle.h: #pragma once.
    - mountain-strafe-cliff-gap.md flipped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
    [explore.h, main.c]
2026-06-18 Fix UI STEPS scaling: chunk count was treated as cm (~6.15x under-scale)
    Firmware STEPS messages carry a MOVE_UNIT *chunk count* (advance_monitored /
    move_batch_until count hops), not centimetres — every emitter (O/FB, the
    explore gaps, F2) sends the same chunk unit, and main.c's S-command sends the
    same `count`. The UI STEPS handler did `steps * SCALE`, treating the chunk
    count as cm, so the robot marker (and its X/Y readout + trail) advanced ~6.15x
    too little for the distance physically driven — observed on HW (UNIT_80 ended
    at X:2.5/Y:-3.2 after a full run).
    Fix (single point): add CM_PER_UNIT = MOVE_UNIT * CM_PER_STEP (~6.15 cm/chunk,
    derived from the existing constants) and scale c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
2026-06-18 Black detection: median read + monitor debounce (kill false positives)
    Diagnosed via a 5-hypothesis panel + adversarial safety audit. Root cause:
    detect_black timed ONE busy-wait half-pulse on a preemptible monitor thread;
    OS preemption mid-measurement inflates the reading, and an inflated CLEAR pulse
    maps toward black -> false-positive-on-white with zero false-negatives (the
    exact reported asymmetry; inflation only ever pushes toward black, which is
    already saturated). Single-sample latch amplified it (one glitch stuck g_black).
    Fixes (preserve zero false negatives; safety-audited SAFE TO DEPLOY):
    - median_pulse_n(): per read = median of DETECT_SAMPLES(5) pulses. Rejects
    preemption outli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
    [explore.h, main_header.h]
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2026-06-18 Fix F STEPS: real distance via non-progress detection (count, not loop iters)
    The F "forward until stop" loop emitted STEPS,count where count was loop
    iterations. The non-blocking stepper drops a batch issued while one is in
    flight, so move_batch_until returns 0 ("done") in ~us with NO motion when the
    robot is pinned at the tape -> count ran to 3161 -> UI plotted ~19,420 cm
    (observed on HW). A cap-only first attempt still emitted STEPS,30 + skipped NOGO
    (rejected by audit).
    Fix (F handler only; move_batch_until untouched): new f_batch_forward() helper
    returns MOVED / STOP(g_black|S) / NOPROG, classifying real motion by TWO signals
    - the poll loop ran >=1 iteration AND stepper_get_steps show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
    [main.c]
2026-06-19 Boot auto-start: systemd unit + idempotent installer (not yet enabled)
    The firmware AUTORUN + student-startup.sh launcher were done, but the OS boot
    wiring was never installed on the board (verified: no systemd unit/rc.local/
    cron/.bashrc hook), so the robot doesn't launch on a real power-up. Add the
    wiring as reproducible repo artifacts (install is a separate on-device step;
    enabling is gated behind a motion-safe bench test).
    - NEW student-startup.service: systemd unit. Type=simple, User=student (binary
    caps give HW access without root; $HOME must be /home/student for robot_id +
    calblack.cfg), no TTY (firmware reads UART0 hardware, not stdin), Restart=
    on-failure + StartLimitBurst=5/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
2026-06-19 Cliff-stop: suspend latching during in-place turns (re-entrant g_black_suspend)
    The downward sensor is mounted ahead of the wheels; during an in-place turn it
    sweeps over side/behind tape that isn't in the travel path, so the monitor would
    latch a spurious g_black that then trips the NEXT forward move. A pure in-place
    turn doesn't translate toward an edge, so suspending cliff *latching* for the
    turn loses no protection (matches the existing "recovery turn not gated" rule).
    Mechanism (explore.h): re-entrant counter g_black_suspend; exp_black_monitor
    skips reading/latching and resets its consec debounce while >0; turn_guard_begin
    /turn_guard_end clear g_black only on the outermost 0<->1 trans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
    [explore.h, main.c]
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2026-06-19 Dual sensor backend: runtime auto-detect XSHUT vs PCA9548A mux
    Adapt the current mission firmware to also run on the OLD mux-based robot, whose
    3 I2C sensors (2x VL53L0X + TCS34725, all natively 0x29) hang off a PCA9548A mux
    at 0x70 instead of being XSHUT-re-addressed to 0x30/0x31. One binary serves both
    boards (matches the ~/robot_id philosophy); mission/motion code UNCHANGED.
    - 3_sensors_header.h: g_sensor_backend (XSHUT|MUX) + g_ch_forward/overhead/color;
    mux_probe / mux_select_channel / mux_scan_vl53_color; one shared transport
    vl53_read_raw_mm(addr, ch) (MUX: select+trigger+60ms+read 0x1E+clear @0x29;
    XSHUT: trigger+30ms+read+clear @addr). The 4 VL53 read helpers swap ONLY their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
    [3_sensors_header.h, main_header.h]
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
